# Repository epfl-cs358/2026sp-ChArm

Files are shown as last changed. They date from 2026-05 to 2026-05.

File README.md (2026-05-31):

# ChArm

<p align="center">
  
  
  
  
  
  
  
  
  
  
</p>

<p align="center">
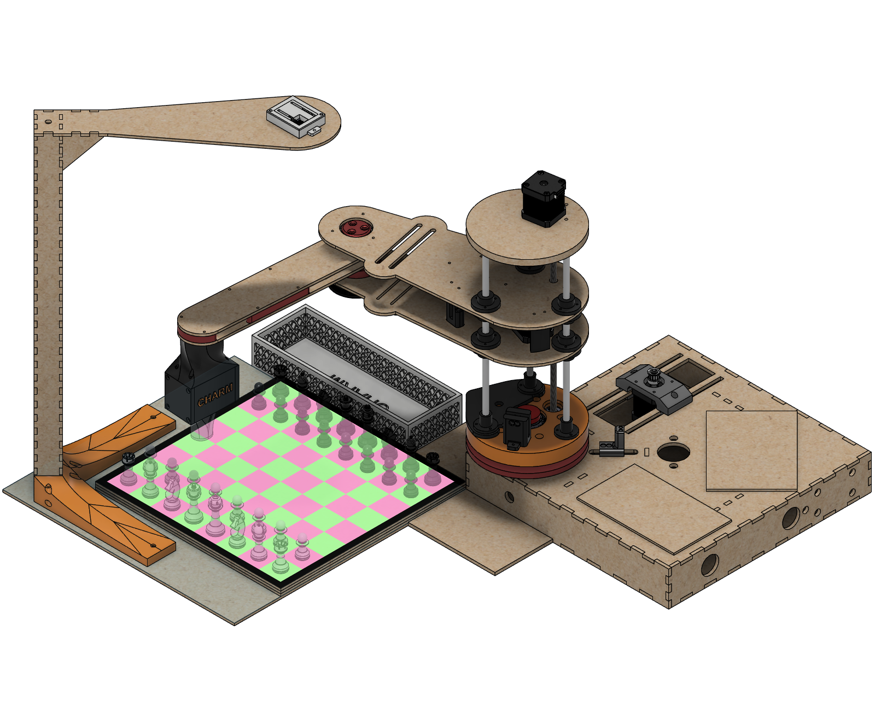
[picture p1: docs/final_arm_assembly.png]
Final arm assembly
  
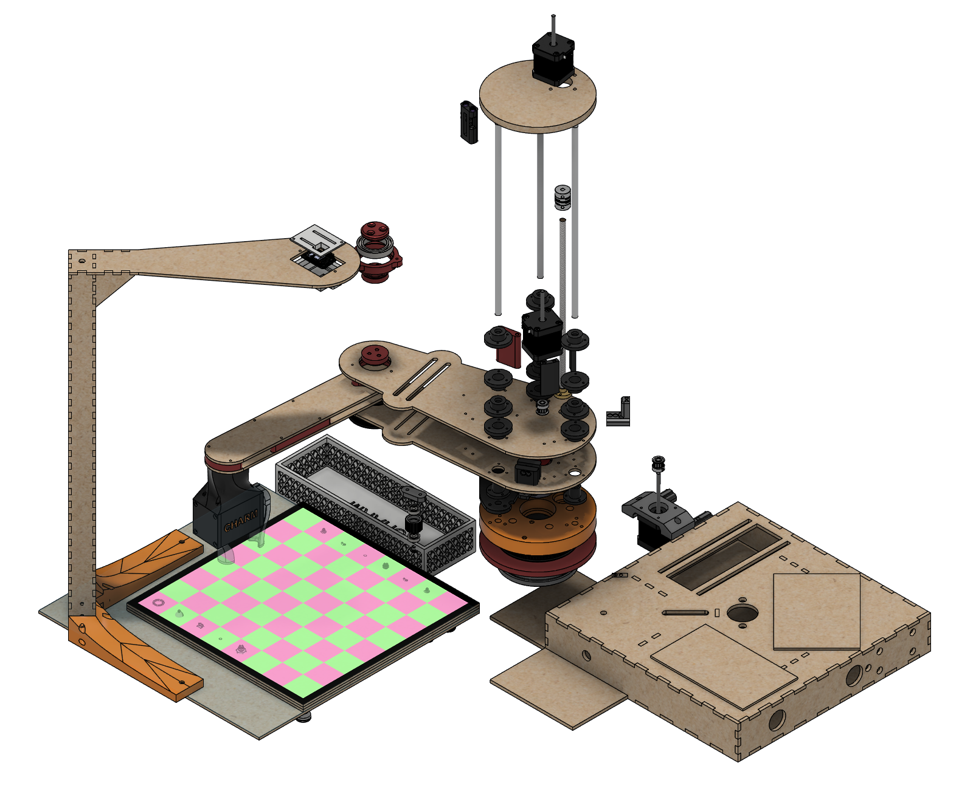
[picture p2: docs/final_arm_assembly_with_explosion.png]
Exploded final arm assembly
  
</p>

> A chess-playing robot arm that sees the board, thinks with Stockfish, and moves the pieces itself.

ChArm is a chess-playing robot arm built around a two-link SCARA arm with a vertical lead-screw Z axis and a servo gripper. An Arduino Mega handles motion, an ESP32-CAM captures the board, an ESP32 UI box drives an on-robot LCD/encoder interface, and a Python host runs the computer vision and chess logic that tie everything together.

<video src="https://github.com/user-attachments/assets/e374c072-53ec-447c-b2c5-00aa87391602" controls width="640"></video>

### Gameplay loop

1. The player initiates arm calibration.
2. The player starts a game and selects a difficulty and a color to play — from either the on-robot LCD/encoder UI or the webapp.
3. The player makes a move on the physical board and confirms it with the rotary encoder (or the **Player done** button in the webapp).
4. The ESP32-CAM captures an image of the board.
5. A computer-vision algorithm and/or a CNN turns that image into two bitmaps describing piece placement.
6. Stockfish computes the best response at the selected skill level.
7. The arm physically moves the chess piece on the board.
8. The turn passes back to the human; repeat from step 3.

This README is the top-level guide to understanding, rebuilding, and running the project.

## Table of Contents

- [Main Features](#main-features)
- [Repository Layout](#repository-layout)
- [Hardware](#hardware)
- [Software Architecture](#software-architecture)
- [How the Game Flow Works](#how-the-game-flow-works)
- [Setup & Installation](#setup--installation)
- [Web Interface](#web-interface)
- [Calibration](#calibration)
- [Common Workflows](#common-workflows)
- [Current Limitations](#current-limitations)
- [Future Improvements](#future-improvements)
- [License](#license)

## Project Overview

The project is organized so that hardware control and chess/vision logic can be developed and tested independently, then integrated through a single Python host.

## Main Features

**Gameplay**
- Plays a full game of physical chess against a human, end to end
- Selectable difficulty (1-20) powered by Stockfish
- Handles normal moves, captures, castling and promotion
- On-robot LCD + rotary-encoder UI — no computer needed to play

**Robot / motion**
- Two-link SCARA arm with a Z lead-screw and servo gripper
- Automatic homing via limit switches and EEPROM-persisted calibration
- Cartesian pick-and-place driven over serial from the Python host

**Computer vision**
- Wi-Fi board capture via ESP32-CAM
- Two-stage perspective rectification and 8×8 grid splitting
- CNN square classifier (empty / white / black) with a classical fallback pipeline
- Self-improving "living dataset" — corrected squares feed the next training cycle

**Move understanding**
- Reconstructs the human's move by matching the observed board against all legal moves
- Validates each observation (legal / unchanged / invalid / ambiguous) and re-captures bad frames

## Repository Layout

```text
2026sp-ChArm/
├── arduino_code/                 PlatformIO project for the Arduino Mega
│   ├── src/                      Firmware entry points and hardware classes
│   ├── esp32_cam_mega_bridge/    ESP32-CAM ↔ Mega bridge sketches
│   └── esp32_ui_box/             ESP32 UI box firmware
├── docs/                         Project documentation
│   └── CAD/                      Project CAD files
├── python_code/                  Python host-side code
│   ├── src/charm/
│   │   ├── vision/               Board calibration and image processing
│   │   ├── chess_engine/         Stockfish integration
│   │   ├── game/                 Board state tracking and orchestration
│   │   ├── arduino/              Serial and UI bridges
│   │   └── utils/                Shared helpers
│   ├── tests/                    Unit tests and demos
│   ├── play_game.py              Full game entry point
│   ├── main.py                   Vision / integration runner
│   └── capture_game_session.py   Raw image capture helper
├── Simulation/                   Prototyping / simulation files
├── webapp/                       Optional Next.js frontend
└── webapp_backend/               Optional FastAPI backend
```
## Hardware

### Mechanical

- **SCARA arm** — two 250 mm links (~500 mm reach), belt-reduced rotational joints
  - J1 (base): 20 → 160 tooth reduction
  - J2 (elbow): 18 → 105 tooth reduction
- **Z axis** — 290 mm-travel vertical lead screw (4-start, 2 mm pitch → 8 mm/rev)
- **Gripper** — servo-driven, 0°–65° open/close span
- **Camera arm** — fixed to the chessboard with a 3D-printed support screwed
  into the board, and a camera mount holds the ESP32-CAM at a stable viewing angle
- **Motors** — 3× 1.8° / 200-step steppers at 16× microstepping (the lead screw runs at 2× microstepping)

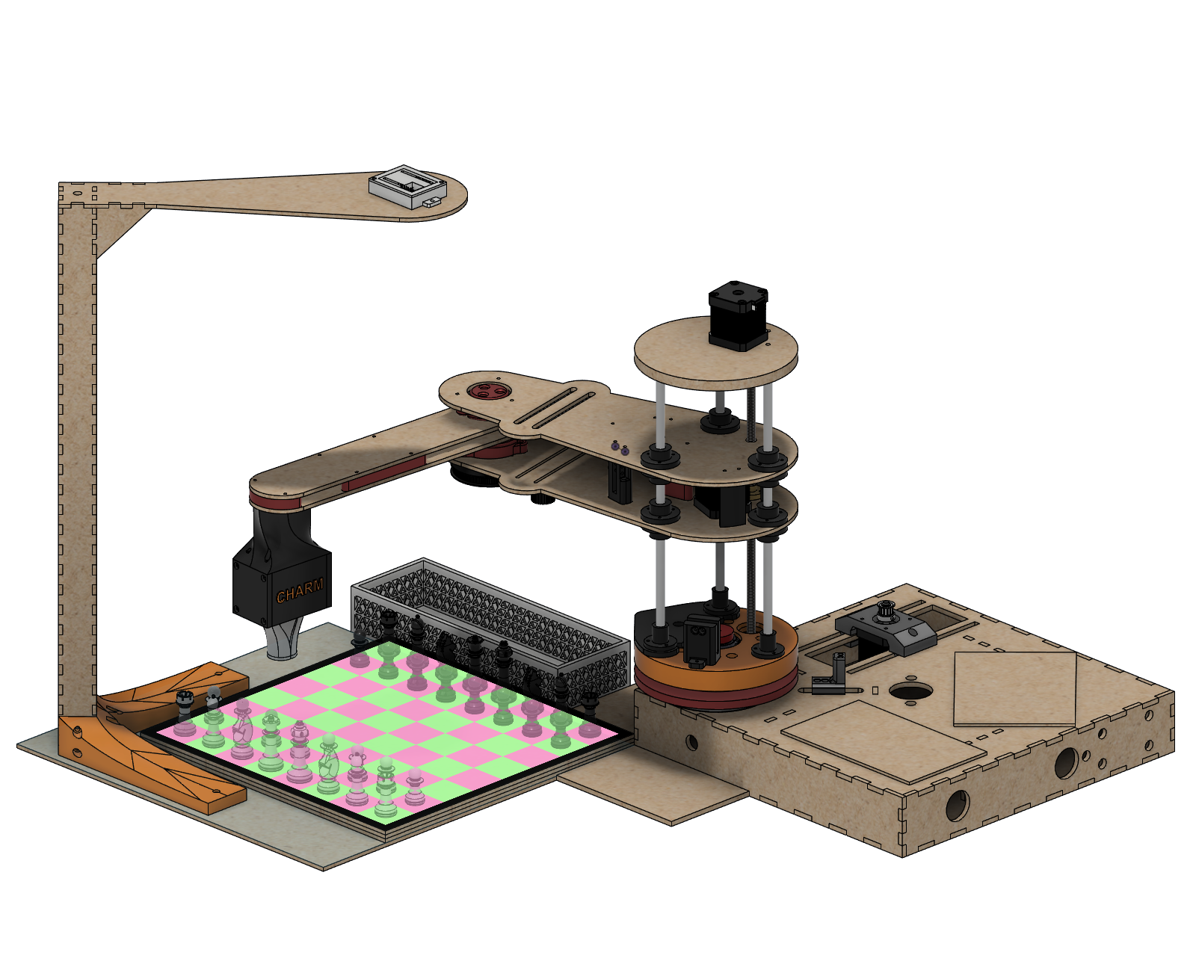
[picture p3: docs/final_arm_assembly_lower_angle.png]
CAD image of the final build


### Electronics and Wiring

**Main Arduino circuit**

- **Arduino Mega 2560** — motion control, calibration, EEPROM persistence
- **ESP32-CAM** (AI-Thinker) — Wi-Fi board capture, HTTP `/capture` endpoint
- **ESP32 UI box** — 16×2 LCD + rotary encoder/button, TCP link to host
- **3× STEP/DIR stepper drivers**
- **4× limit switches** — J1 home, 2× J2 home, Z bottom; wired to a stripboard in a pull-up configuration and read by the Arduino
- **Power supply** — 12 V at 5 A for the motors (through the CNC shield); a buck converter supplies the 5 V components (camera, servo, etc.)

**UI box**

- Needs only 5 V power, distributed to the correct pins on a stripboard. The data pins of the LCD and the button connect to an ESP32 that handles transmission to the host.

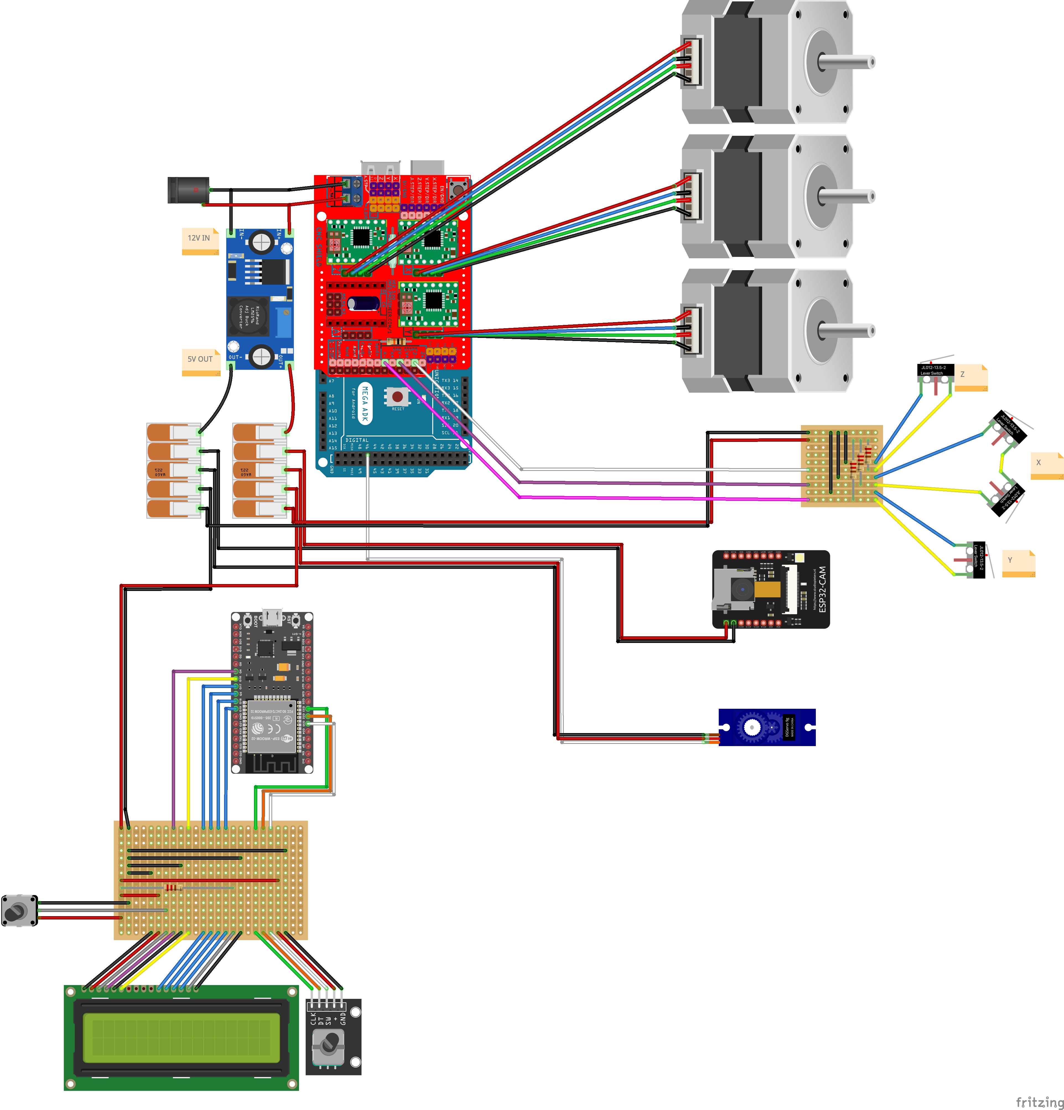
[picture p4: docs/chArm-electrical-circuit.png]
Electrical Circuit


### Fabrication Tools

- **Metal lathe and drill press** — machining the flanges at the base
- **3D printer** — most of the parts around the arm
- **Laser cutter** — structural parts that would not print well
- **Soldering equipment** — wiring and connectors

### CAD Overview

The CAD files for the printed and laser-cut parts live in [docs/CAD/](docs/CAD/).

**Build order (high level)**

1. Machine the base flanges, on the lathe/drill.
2. Print the 3D printed parts available in the CAD files
3. Laser cut the DXF files in the CAD files
3. Cut 3 320 size 8mm metal rods
4. There are a lot of heat inserts needed so make sure you put them nicely.
5. Once the heat inserts are inserted you can start building the 6 main modules to assemble (box, base, arm, lcd, display, camera arm, chessboard)
6. Next step is to solder and add jst connectors to the 4 main electrical components (one camera power stripboard, 1 ui box stripboard, the limit switch themselves and its pull up resistor stripboard)
7. Now that everything is assembled just wire up the electronics as in the diagram
8. flash the firmware using the ./install.sh utility
9. start playing

### Configuration Files

Two firmware headers hold the values worth checking whenever the robot is rebuilt or re-tuned:

- [config.h](arduino_code/src/hardware/src/config.h) — motion and geometry constants (gear ratios, link lengths, steps/mm, gripper angles, pick/place heights).
- [pins.h](arduino_code/src/hardware/src/pins.h) — the microcontroller pin assignments.

## Software Architecture

ChArm is a distributed system. A Python backend orchestrates the game and talks
to a web/embedded frontend, three microcontrollers, and a chess engine. The
backend (`webapp_backend/api_server.py`, a FastAPI service on port `8765`) is
the single source of truth: both the webapp and the on-robot LCD drive the
**same** game session through it.

```mermaid
flowchart LR
    WEB["Webapp<br/>(Next.js :3000)"]
    UI["On-robot UI<br/>ESP32 UI box"]
    CAM["ESP32-CAM"]
    ARM["Arduino Mega<br/>SCARA arm"]

    subgraph HOST["Python host — FastAPI backend (:8765)"]
        GAME["game/<br/>state tracker + controller"]
        VIS["vision/<br/>CV router → classical / CNN"]
        ENG["chess_engine/<br/>Stockfish + evaluation"]
        ADP["arduino/ + robot_adapter"]
    end

    WEB <-->|HTTP / REST| HOST
    UI <-->|TCP| HOST
    CAM -->|JPEG over Wi-Fi| VIS
    GAME --> VIS
    GAME --> ENG
    GAME --> ADP
    ADP -->|USB serial| ARM
```

The rest of this section documents each layer, bottom-up: the **embedded
firmware** on the microcontrollers, then the **Python host** modules.

### Embedded Firmware

Three microcontrollers each run their own firmware: the Arduino Mega for motion,
the ESP32-CAM for board capture, and the ESP32 UI box for the player interface.

#### Arduino Mega — motion control

The main Arduino entry point is [arduino_code/src/main.cpp](arduino_code/src/main.cpp).

It is responsible for:

- initialising steppers, joints, gripper, lead screw, and limit switches on boot
- homing all axes via limit switches before any motion
- running a guided 3-corner board calibration wizard (`cal` command) and saving the result to EEPROM
- receiving serial commands from the Python host and executing them
- translating high-level commands like `pick <piece> <square>` and `put <piece> <square|trash>` into Cartesian pick-and-place sequences
- supporting direct movement commands

Key hardware abstractions are in [arduino_code/src/hardware/src/](arduino_code/src/hardware/src/):

- `ScaraArm`: top-level arm controller; exposes `pickAt`, `placeAt`, `moveXY`, `moveXYZ`, `goHome`
- `ScaraKinematics`: inverse/forward kinematics for the two-link SCARA geometry
- `ScaraJoint`: per-joint stepper with gear-ratio scaling and angle tracking
- `LeadScrew`: Z-axis stepper with mm-to-step conversion
- `StepperXYZ`: low-level STEP/DIR stepper driver
- `Gripper`: servo-driven gripper with open/close angles
- `LimitSwitch`: debounced limit switch reader used during calibration

The PlatformIO environments are defined in [arduino_code/platformio.ini](arduino_code/platformio.ini).

#### ESP32-CAM — board capture

The ESP32-CAM firmware is in [arduino_code/esp32_cam_mega_bridge/esp32_cam_code_mit.ino](arduino_code/esp32_cam_mega_bridge/esp32_cam_code_mit.ino).

Upload it to an AI Thinker ESP32-CAM board with the Arduino ESP32 core. Before flashing, set the `ssid` and `password` constants in the sketch to the Wi-Fi network used by the Python host.

At runtime, the board:

- connects to Wi-Fi and starts an HTTP server on port `80`
- exposes `/capture` as a JPEG image endpoint for browser or Python capture
- exposes `/status` as a small JSON health endpoint
- exposes `/` as a camera settings endpoint

#### ESP32 UI box — player interface

The main ESP32 entry point is [arduino_code/esp32_ui_box/esp32_ui_box.cpp](arduino_code/esp32_ui_box/esp32_ui_box.cpp).

It is responsible for:

- connecting to Wi-Fi
- hosting a TCP server on port 8765 for bidirectional communication with the Python host
- driving the 16×2 LCD display
- reading the rotary encoder and push button and converting them to `INPUT_NEXT`, `INPUT_PREV`, and `INPUT_SELECT` events
- running the `UIState` mode state machine and forwarding commands to Python

Key abstractions are in [arduino_code/src/hardware/src/](arduino_code/src/hardware/src/):

- `UIState`: 11-mode state machine holding the current screen, game status, turn, and selected values
- `UIControllerESP32`: ties it all together: reads encoder events and TCP messages, drives `UIState` transitions
- `LCDDisplay`: 16×2 display driver
- `ButtonInput`: rotary encoder decoder, emits `INPUT_NEXT`, `INPUT_PREV`, `INPUT_SELECT`

From the player's perspective the flow is:

1. The LCD shows `Main Menu`; scroll with the encoder to `> Start Game`, `> Calibration` or `> Manual Control`, and press whichever to select.
2. After selecting `> Start Game`, The LCD shows `Difficulty` / `<n>`; scroll to adjust and press to confirm difficulty level.
3. The LCD shows `Play as...` / `> White` or `> Black`; scroll and press to confirm.
4. During the game the top line shows the turn (`White Turn` / `Black Turn`, prefixed with `CHECK` if in check); the bottom line reflects the bot's activity (`BOT thinking...` and `Bot moving` / `<uci.move>`). When it is your turn, the bottom line shows `If done press OK`; make your move on the board and press the button to confirm.
5. When the game ends the LCD shows `White Wins!`, `Black Wins!`, `Stalemate`, or `Draw`.
6. If something goes wrong at any point (illegal move, board detection failure, etc.) the top line shows `Illegal move !` or `Set up ERROR` and the bottom line shows the error detail; press the button to clear it and retry.

Before flashing, edit `WIFI_CREDENTIALS` in [arduino_code/esp32_ui_box/esp32_ui_box.cpp](arduino_code/esp32_ui_box/esp32_ui_box.cpp). The LCD shows the ESP32 IP address after Wi-Fi connects; enter that address in the webapp so the host can reach the UI box.

The UI box exchanges TCP commands with the Python host. The ESP32-to-Python commands are `CHECK_BOARD`, `PLAYER_DONE`, `SET_COLOR <n>`, `SET_DIFFICULTY <n>`, `CALIBRATION`, `PROMOTION_CHOICE <piece>` (user's pawn-promotion selection: q/r/b/n), `BOARD_OK_ACK`, `BOARD_FAIL_ACK`, and `BOARD_TIMEOUT`. In manual-control mode the ESP32 also sends `MANUAL_JOINT1_FWD`, `MANUAL_JOINT1_BWD`, `MANUAL_JOINT2_FWD`, `MANUAL_JOINT2_BWD`, `MANUAL_Z_FWD`, `MANUAL_Z_BWD`, `MANUAL_GRIPPER_OPEN`, and `MANUAL_GRIPPER_CLOSE`. Python replies with status updates such as `BOARD_OK`, `BOARD_FAIL`, `BOT_THINKING`, `BOT_MOVE <uci>`, `BOT_MOVING`, `BOT_PROMOTING <piece>`, `PLAYER_TURN_WHITE`, `PLAYER_TURN_BLACK`, `MOVE_DONE`, `CHECK`, `PROMOTION_NEEDED`, `GAME_OVER <reason>`, `ERROR_MSG <message>`, and `SET_MODE <n>`.

The PlatformIO environment is defined in [arduino_code/esp32_ui_box/platformio.ini](arduino_code/esp32_ui_box/platformio.ini).

### Python Host

At runtime the FastAPI backend wires together four packages under
`python_code/src/charm/`:

| Package | Responsibility |
|---|---|
| `vision/` | Capture → rectify → classify into two 8×8 occupancy/color bitmaps |
| `game/` | Track board state, reconstruct the human's move, orchestrate turns |
| `chess_engine/` | Stockfish move selection and position evaluation |
| `arduino/` | Serial/TCP bridges to the SCARA arm and the UI box |

#### Computer Vision (`vision/`)

The vision stack turns a single raw ESP32-CAM frame into two 8×8 bitmaps (white
pieces and black pieces) for the move tracker. It runs **two interchangeable
pipelines**, a classical CV algorithm and a trained CNN, that share the same
pre-processing and the same bitmap output format, selected at runtime by a
router (`cv_router.py`).

Key files: `pipeline.py`, `board_detector.py`, `grid_splitter.py`,
`occupancy_detector.py`, `piece_color_detector.py`, `cnn_classifier.py`,
`cv_router.py`, `four_point_calibration.py`, `calibrated_pipeline.py`.

##### Geometric pre-processing (shared)

Both pipelines start from the same stage, which transforms a raw,
perspective-distorted camera image into a normalized 8×8 board representation.

**Two-stage perspective warping** — two sequential homographies align the board:

1. **Global warp**: the four calibrated outer corners map to an 800×800 square.
2. **Inner refinement**: internal grid intersections refine that warp,
   correcting lens distortion and small geometric error so every square lands
   consistently.

**Grid splitting**

The refined image is divided into 64 `SquareCell` objects. Each cell contains:

- an RGB crop of one board square
- its row and column indices within the 8×8 grid

##### Classical pipeline — the vision algorithm

The high-level flow of the classical CV pipeline is:

1. Run occupancy detection on each cell to decide whether it contains any piece.
2. Run color detection only on occupied cells to classify them as white or
   black.
3. Assemble the final white/black 8×8 bitmaps and save debug overlays for
   inspection.

**Occupancy detection**

For each square, the detector looks at a central region of interest instead of
the whole cell. The ROI is converted to grayscale, broad lighting gradients are suppressed by subtracting a heavily blurred version of the image, and then CLAHE is applied before scoring with the edge density with Canny .

The final occupancy score combines local contrast and Canny edge density.

For occupancy, `occupancy_threshold` decides whether a square is occupied.
Raising it reduces false positives, lowering it helps detect weaker pieces. In our setup, empty squares are usually around `0-5`, occupied squares around `20+`, and the active threshold is `12.0`.

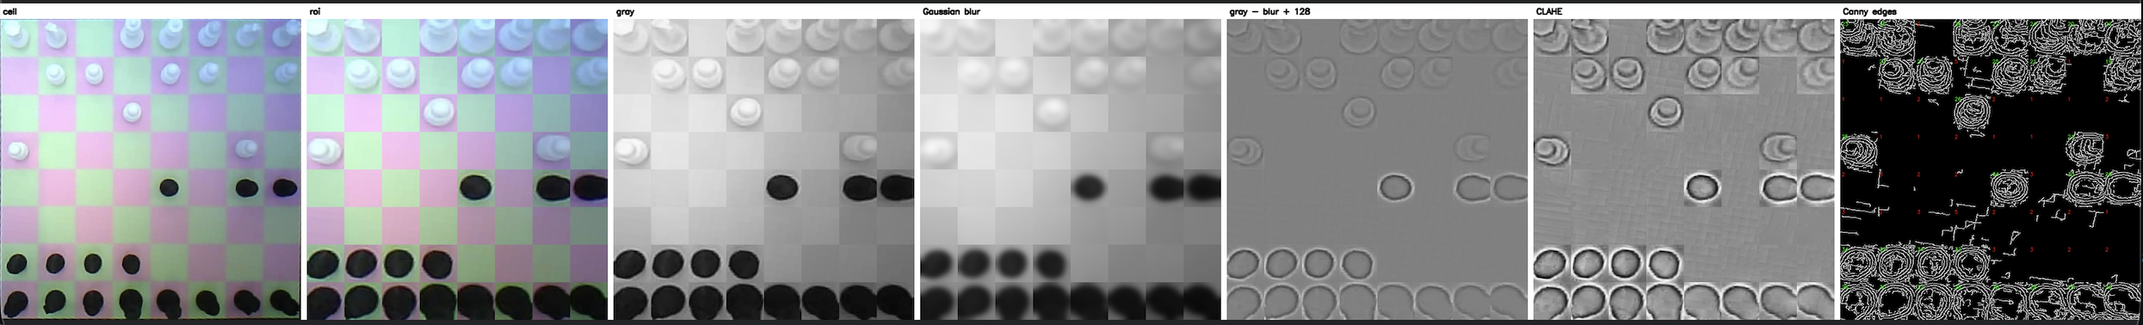
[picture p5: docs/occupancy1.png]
Occupancy Pipeline : from raw picture to processed.

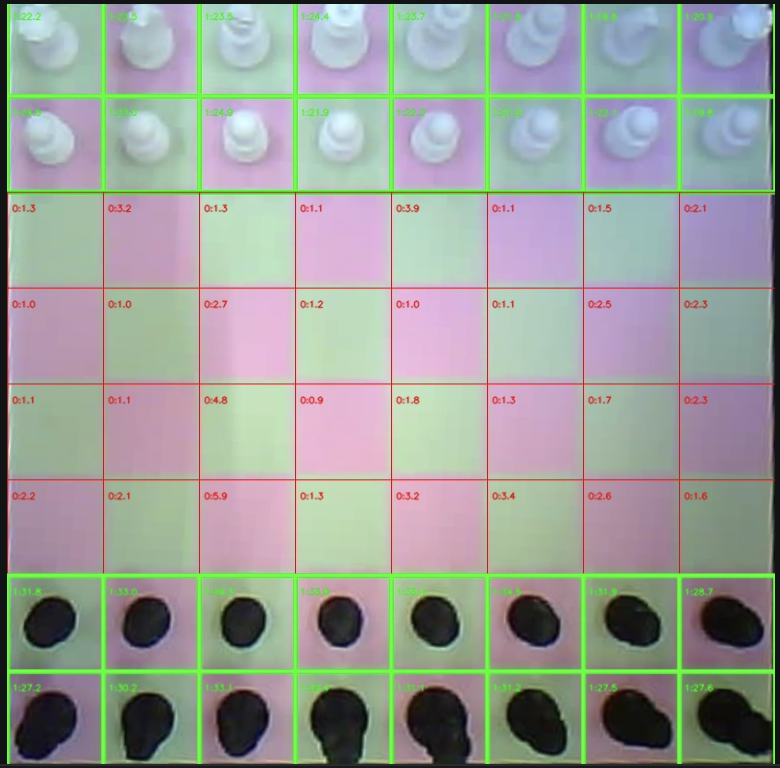
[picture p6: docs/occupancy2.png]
Final processed image with occupied tiles flagged


**Piece-color detection**

Only cells already marked as occupied are classified by color. For each occupied
cell, the detector inspects a smaller central ROI where the body of the chess
piece is most likely to appear. It converts that ROI to grayscale and uses the
75th percentile brightness as the color score.

For piece color, raising the threshold makes the detector more conservative
about white pieces, so borderline pieces are more likely to be classified as
black. Lowering the threshold makes pieces easier to classify as white. In our
setup, `90` separates white pieces around `200` from black pieces around `40`.

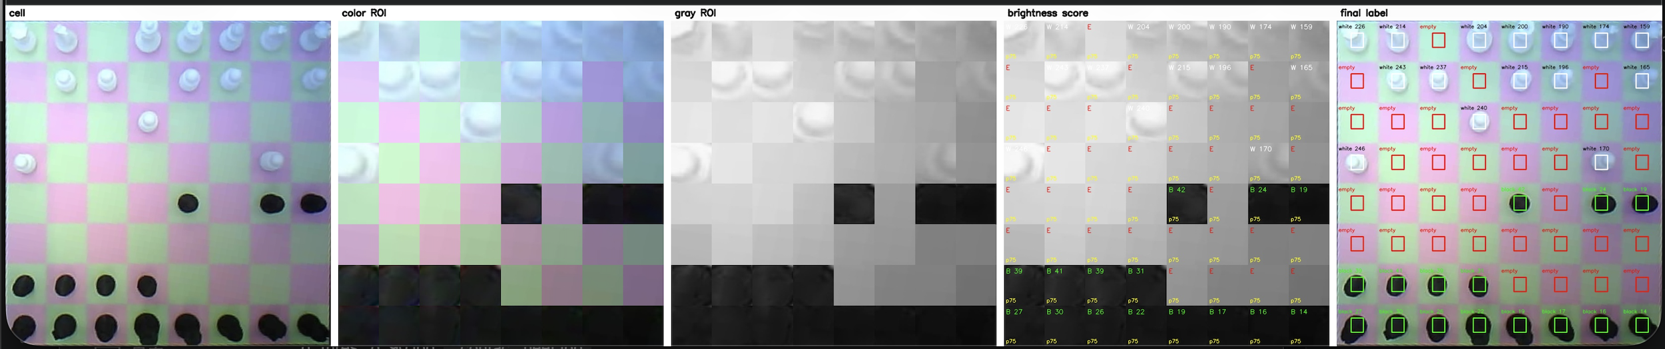
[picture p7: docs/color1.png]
Color detection pipeline, from raw picture to colors detected


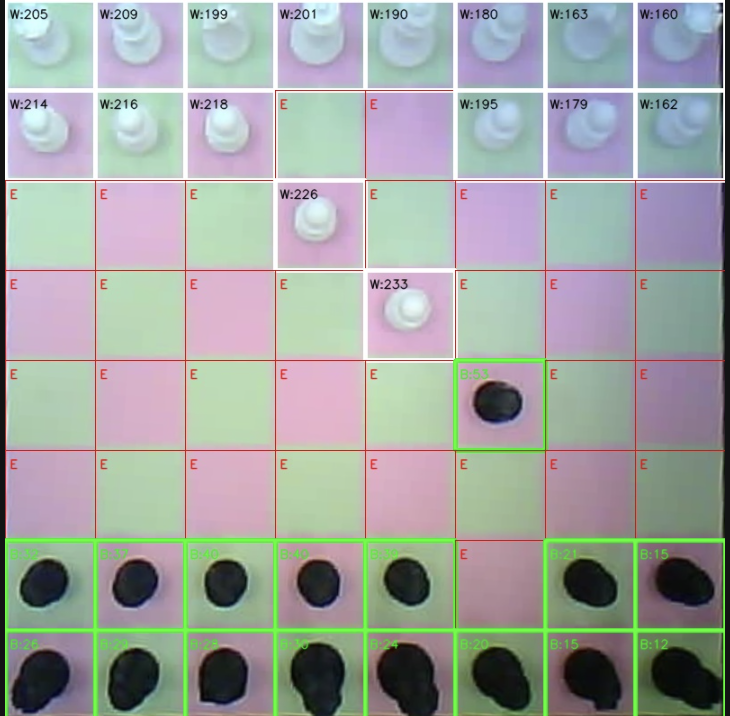
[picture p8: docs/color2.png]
Final color detected image with black and white pieces flagged


##### CNN classifier

The CNN classifier (`cnn_classifier.py`) replaces step 4 of the classical
pipeline (occupancy + color thresholds) with a single learned model trained on
the ChArm board and piece set by `train_cnn.py`. `CnnBoardClassifier` wraps a
trained **Keras / TensorFlow** model, loaded once and reused across requests.

**Model objective**

The classifier predicts one of three classes for each square:

- `empty`
- `white`
- `black`

**Model structure**

A lightweight Keras CNN runs efficiently on CPU:

- input: normalized RGB square image
- three convolutional blocks with increasing filter counts
- max-pooling for spatial downsampling
- global average pooling for robustness to slight piece offsets
- softmax output over the three classes

**Batch inference**

Instead of processing cells individually, all 64 board squares can be stacked into a single tensor and passed through the model in one forward pass. This allows the whole board to be evaluated efficiently and consistently.

##### Primary / fallback routing (`cv_router.py`)

To stay robust under shadows, blur, or unclear piece placement, the router
attempts multiple captures and evaluates them in sequence:

1. first attempts use the primary pipeline (typically the CNN)
2. if repeated fresh captures still fail to produce a valid board update, the
   system falls back to the other pipeline (the classical algorithm)
3. only observations that can be matched to a valid board-state transition are
   accepted

**Validation rule**

An observation is only accepted if the `BoardStateTracker` can interpret it as:

- a unique legal move

If the result is invalid or ambiguous, the frame is rejected and a new capture
is requested.

##### Living dataset and continuous improvement

The CNN improves from real operation through a correction loop: when a square is
misclassified, the user relabels it, the cell crop is added to the dataset, and
the next training run includes it. Over time the model specializes to the actual
board texture, lighting, pieces, and camera noise — reducing reliance on
hand-tuned thresholds.

#### Move Understanding (`game/`)

The `game/` package is the reasoning layer between camera perception and chess
rules. Vision tells the system what the physical board appears to contain;
`game/` decides whether that observation makes sense as a legal chess position
and updates the internal `python-chess` board accordingly.

A key design decision is to keep the camera's job simple. ChArm does **not** try
to visually identify whether a piece is a queen, bishop, knight, and so on.
Instead, the vision stack outputs two 8×8 occupancy maps:

- white-occupied squares
- black-occupied squares

The missing piece identity is recovered from context. Since the software already
knows the previous legal chess position, `BoardStateTracker` can simulate every
legal move from that position, convert each candidate board into the same
white/black occupancy format, and compare it against the observed bitmaps. If
only one legal move explains the new board, the move is accepted. This avoids the
fragile problem of recognizing six piece types from a noisy camera image and
turns move detection into a rules-based consistency check.

Each scan is classified into one of four tracker states:

| Status | Meaning |
|---|---|
| `accepted_legal_move` | One legal move uniquely explains the observed board. The move is pushed to the internal board. |
| `unchanged_position` | The observed board still matches the previous position, so no move has been made yet. |
| `invalid_observation` | No legal move explains the observation. The frame is rejected and the user is asked to correct the board or scan again. |
| `ambiguous_observation` | Multiple legal moves produce the same occupancy result. The frame is rejected because the move is not uniquely recoverable. |

Key files and main ideas:

##### `state_tracker.py`

This is the core of move understanding. It keeps the current `python-chess`
board and tries to explain a new camera observation using legal chess moves.

The main idea is simple: instead of asking the camera "which exact piece is on
each square?", we ask the chess engine "which legal move would make the board
look like this?" For each legal move, the tracker simulates the move, turns the
candidate board into white/black occupancy bitmaps, and compares those bitmaps
with the camera result.

If one move matches, the tracker accepts it and updates the board. If nothing
matches, the scan is rejected. If several moves look the same from occupancy
alone, the scan is marked ambiguous. This file is intentionally independent from
the camera, webapp, LCD, and robot arm, which makes the logic much easier to
test and reuse.

One special case is promotion: the camera cannot tell whether a pawn promoted to
a queen, rook, bishop, or knight because all of those look like "one piece on
the promotion square" in the bitmap. The tracker uses queen promotion as the
default during inference, and the UI can correct the final piece choice later.

##### `vision_integration.py`

This file is the bridge between image processing and the tracker. It runs the
board-vision pipeline on an image, takes the resulting white/black bitmaps, fixes
orientation if needed, and passes the bitmaps into `BoardStateTracker`.

The reason for this small adapter is cleanliness. The tracker should not care
where the bitmaps came from, and the vision code should not need to know the
details of chess move inference. If the camera calibration or vision pipeline
changes later, this is the main place where the two sides reconnect.

##### `game_session.py`

`GameSession` manages one full logical game. It sits one level above the tracker:
the tracker answers "what move happened?", while the session keeps track of
"has the game started?", "which color is the player?", "whose turn is next?",
and "what should the system tell the user?"

It validates the initial board, stores the player and robot colors, processes
the player's move, asks Stockfish for the robot's move, records the move history,
and commits the robot move after the arm has executed it. It also converts low
level tracker results into clearer messages, such as unchanged board, illegal
move, ambiguous scan, or the player still being in check.

The useful design choice is that `GameSession` still does not directly control
the camera or motors. It receives an image or bitmap, updates the logical chess
state, and returns a structured result. That means the game logic can be tested
without plugging in the real hardware.

A normal session looks like:

```text
validate initial board
    ↓
choose player color
    ↓
detect player move
    ↓
compute robot move
    ↓
arm executes robot move
    ↓
commit or verify robot move
```

##### `game_controller.py`

`GameController` connects the clean game logic to the actual running system. It
listens to events from the ESP32 LCD box, calls the CV router when a board scan
is needed, talks to `GameSession`, sends robot moves to the Arduino layer, and
keeps the webapp updated.

This is where the real-world flow is coordinated: checking the initial board,
handling "player done", retrying CNN/classical vision scans, showing errors,
displaying check/game-over states, applying difficulty settings, handling
promotion choices, and starting the robot move without freezing the UI.

The main idea is separation: if someone wanted to rebuild ChArm with a different
screen, camera trigger, or robot controller, they could keep the tracker and
session logic mostly unchanged and rewrite this controller layer for their own
hardware.

A typical player-move update follows this path:

```text
player presses done
    ↓
CV router captures board image
    ↓
CNN or classical vision pipeline
    ↓
white/black occupancy bitmaps
    ↓
BoardStateTracker
    ↓
accepted / unchanged / invalid / ambiguous result
    ↓
GameSession and GameController update the game flow
```

This separation is useful for debugging. Vision can be inspected as bitmaps and
debug overlays, while the move tracker can be tested without a camera by feeding
synthetic bitmaps generated from known chess moves.

#### Chess Engine (`chess_engine/`)

The `chess_engine/` package is the robot's chess-decision layer. It receives the
current `python-chess` board from the session, asks Stockfish to search that
position, and returns the move the robot should play.

Key files:

- `best_move.py` — opens a Stockfish UCI process, applies the selected strength
  settings, searches for a move under the configured think time, and returns a
  `python-chess` move object. Difficulty can be controlled through Stockfish
  skill level or through the `UCI_LimitStrength`/`UCI_Elo` options.
- `evaluation.py` — runs evaluation probes for the webapp and LCD feedback. It
  reports centipawn or mate scores, best-move suggestions, winning side,
  approximate win percentage, and player move ratings such as `Excellent`,
  `Mistake`, or `Blunder`.

The engine layer is intentionally separated from the rest of the game logic. The
tracker decides what the human physically did; Stockfish decides what the robot
should do next. Because those responsibilities are separate, the team can tune
difficulty, change think time, replace the engine, or adjust evaluation feedback
without touching the vision or move-reconstruction code.

A normal engine call looks like this:

```text
current python-chess board
    ↓
best_move.py
    ↓
Stockfish search at selected difficulty
    ↓
robot move in UCI format, e.g. e7e5
    ↓
GameController sends the move to the robot-motion layer
    ↓
GameSession commits the robot move to the internal board
```

After Stockfish returns a move, the game controller converts it into the robot's
physical pick-and-place sequence using the pre-move board state, so captures,
castling, en passant, and promotions can be handled consistently at the boundary
between chess logic and robot motion.

#### Hardware Bridges (`arduino/`)

- `arduino_bridge.py`: sends Cartesian pick-and-place commands to the Arduino Mega over USB serial
- `uiController_bridge.py`: `ArduinoUIControllerLink`, the TCP link to the ESP32 UI box

The backend's `webapp_backend/robot_adapter.py` owns the serial connection and a
lock, so the LCD and the webapp can both drive the arm without colliding.

## How the Game Flow Works

At a high level:

1. `./start.sh` launches the host backend (`webapp_backend/api_server.py`) and the webapp.
2. The backend connects to:
   - the **ESP32 UI box** over TCP (`ArduinoUIControllerLink`)
   - the **Arduino Mega** over USB serial (`robot_adapter`)
   - the **ESP32-CAM** over Wi-Fi for board capture

   The LCD and the webapp share this one backend, so either can drive the game.
3. The user starts the game from the UI (or webapp) and picks color and difficulty.
4. The backend validates the initial board from a calibrated image.
5. After each player move, the backend:
   - captures a new board image,
   - runs the vision pipeline,
   - reconstructs the move with `python-chess`,
   - validates whether the observation is acceptable.
6. Stockfish computes the robot response.
7. The Arduino executes the robot move physically.

The tracker statuses currently used by the move-validity layer are:

- `accepted_legal_move`
- `unchanged_position`
- `invalid_observation`
- `ambiguous_observation`

## Setup & Installation

We provide a cross-platform setup wizard and launcher scripts that run on **Windows, macOS, and Linux**.

### What the Setup Wizard Does
The setup wizard automates the entire installation and deployment pipeline:
1. **Prerequisite Check**: Verifies that Python 3 and Node.js/NPM are present on your machine.
2. **Python Environment**: Automatically creates a local virtual environment (`venv/` in the root) and installs all required dependencies (including **PlatformIO** so you do not need Arduino IDE).
3. **Frontend Dependencies**: Installs React/Next.js frontend libraries in the `webapp/` folder.
4. **Firmware Wizard**: Runs a step-by-step firmware compiling and uploading flow. It automatically scans your computer's USB/Serial ports, displays them, and lets you select the correct port for:
   - **ESP32-CAM** (Mega Bridge)
   - **ESP32 UI Box**
   - **Arduino Mega 2560**
5. **Startup Shortcuts**: Creates root launcher scripts (`start.sh` for Linux/macOS, `start.bat` for Windows) targeting the virtual environment.

---

### Step 1: Run the Installation Script

1. **Linux / macOS**:
   ```bash
   ./install.sh
   ```
2. **Windows**:
   Double-click or run from CMD:
   ```cmd
   install.bat
   ```

Follow the prompts to configure Node dependencies and select your serial ports to flash the hardware controllers.

> [!NOTE]
> Make sure to install Stockfish separately if it is not already available on your machine:
> - **Debian/Ubuntu**: `sudo apt install stockfish`
> - **macOS**: `brew install stockfish`
> - **Windows**: Download the binary from the official Stockfish site and add it to your PATH.

---

### Step 2: How to Launch the App

Once setup is complete, you can launch both backend and frontend servers with a single command:

1. **Linux / macOS**:
   ```bash
   ./start.sh
   ```
2. **Windows**:
   ```cmd
   start.bat
   ```

This will automatically load the virtual environment and start the FastAPI webserver and React dashboard concurrently.

## Web Interface

Once the app is running, open the webapp at <http://localhost:3000>. It is the
control center for the whole robot: you can play a game, configure the vision
pipeline, train and activate a CNN, label training data, and calibrate the arm —
all without touching a terminal.

### Built-in Guide page

The webapp ships with its own **Guide** page that walks through every screen,
explains what each control does, and ends with a "Starting a Game" checklist. It
lives at <http://localhost:3000/guide> and is the most up-to-date, canonical
reference for using the interface — start there rather than memorizing the
sections below.

### Pages at a glance

| Page | Route | What it's for |
|---|---|---|
| Dashboard | `/` | Play a game, live board view, arm calibration, **Run LCD** sync |
| Vision Pipeline | `/lab` | Debug the classical CV output stage-by-stage; tune the occupancy threshold and warp |
| Vision Settings | `/lab/vision-settings` | CV router (classical vs. CNN), auto-save of training frames, active CNN model |
| Labeling Wizard | `/lab/labeling` | Build labeled datasets via arm-driven capture or bulk painting |
| CNN Wizard | `/lab/cnn` | Train a model on a dataset and activate it for live play |
| SCARA Calibration | `/robot` | Teach the arm the board corners (a1, h1, h8) |
| Guide | `/guide` | In-app walkthrough of all of the above |

The Serial Monitor bar at the bottom of every page streams the commands sent to
the Arduino arm (TX) and its responses (RX) for live debugging.
## Calibration

The camera image contains a lot more than the chessboard: table texture, shadows,
robot parts, board borders, lens perspective, and sometimes pieces near the edge
of a square. Instead of trying to detect the 8×8 grid directly from that noisy
full image, ChArm uses a two-step crop-and-warp calibration.

The idea is:

1. first find the outer board area and warp it into a square top-down view,
2. then select the cleaner inner playing area used for the 8×8 grid.

This makes the vision pipeline more stable because the later CNN/classical
detectors only see the board region they actually need, not the surrounding
background noise.

The Python vision stack saves this setup in two JSON files:

- `python_code/board_calibration.json`
- `python_code/inner_warp_calibration.json`

The related vision code lives in:

- `python_code/src/charm/vision/four_point_calibration.py` — stores and applies
  the outer-board and inner-warp perspective transforms.
- `python_code/src/charm/vision/calibration_config.py` — defines the default
  calibration file locations.
- `python_code/calibrate_aruco.py` — can generate the calibration files from
  ArUco markers.
- the webapp manual calibration flow — lets the user adjust and save the two
  calibration steps visually.

The typical workflow is:

1. capture a clear image of the board,
2. mark the four outer board corners,
3. warp the image into a first top-down board view,
4. mark the inner playable area more precisely,
5. save both calibration JSON files,
6. run the game pipeline using the refined board crop.

After calibration, every live image follows the same path: raw camera photo →
outer board warp → inner refined warp → 64 square crops. This is the main reason
the rest of the vision system can stay simple and consistent.

## Common Workflows

### Play a game

This is the normal way to run ChArm. From the repo root:

```bash
./start.sh
```

`start.sh` runs `npm run dev`, which launches **both** the Python vision/game
backend (`webapp_backend/api_server.py`, port `8765`) and the Next.js frontend
(port `3000`). Then either:

- open the webapp at <http://localhost:3000>

From there: calibrate the arm (mandatory), start a game, pick color and difficulty, make
your move on the physical board, and confirm it. The backend captures the board,
runs the vision pipeline, validates your move, asks Stockfish for the reply, and
drives the arm.

### Calibrate the board (vision)

The board calibration is done from the webapp:

1. Click **Manual calibration**.
2. Capture a new picture.
3. Adjust the outer corners, then the inner warp — click **Save** and
   **Calibrate** between each step.

This writes `board_calibration.json` and `inner_warp_calibration.json`, which the
game pipeline then loads automatically.

### Improve the CNN (living-dataset loop)

Training data accumulates in `python_code/labeled_datasets/`. There are two ways
to grow it.

**During play (passive)** — every validated board frame is sliced into 64
labeled cell crops and saved automatically, so the dataset grows just by playing.

**With the labeling wizard (webapp)** — the webapp has a dedicated labeling page
for building datasets quickly and consistently. It supports two capture modes:

- **Autonomous (arm-driven) capture** — the robot picks pieces from a source
  square and places them across the board on its own, homing out of frame before
  each shot. This produces large, correctly-labeled datasets with no manual
  effort, since the label is whatever the arm just placed.
- **Bulk painting** — the "painted-board" mode: set up many pieces at once, paint
  each square's label (empty / white / black) on the on-screen grid, then hit
  capture. One photo yields a labeled crop for every painted square.

<table>
  <tr>
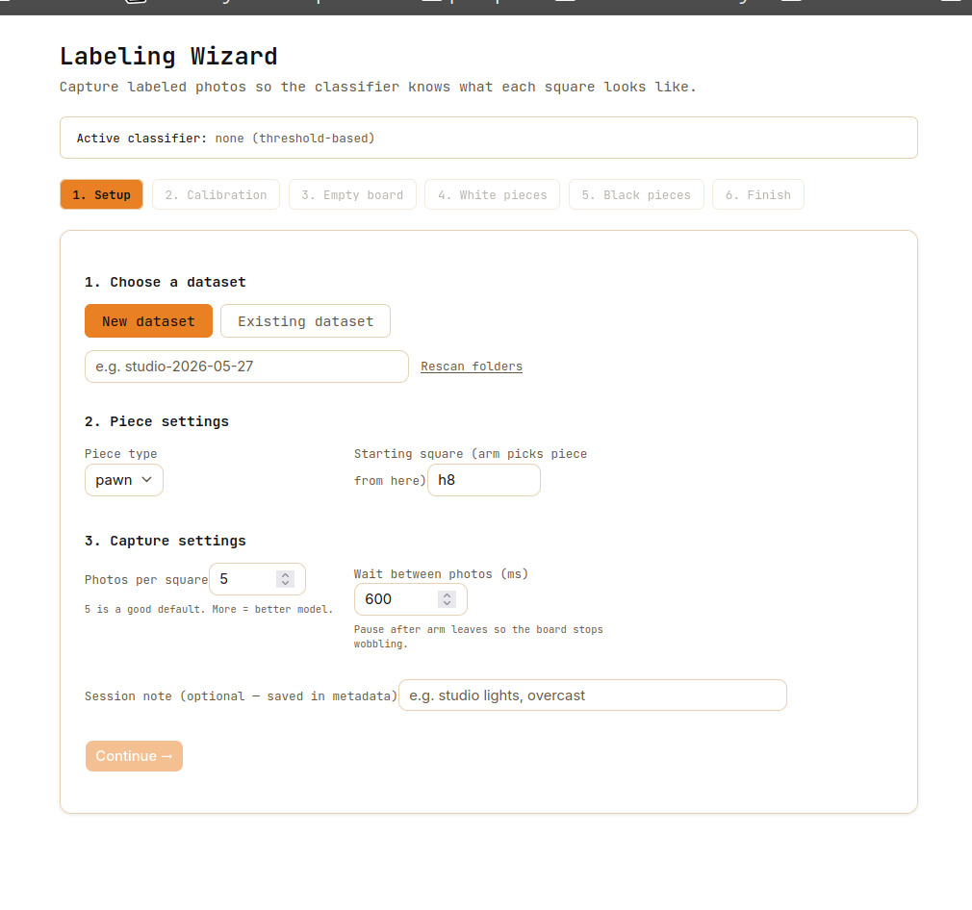
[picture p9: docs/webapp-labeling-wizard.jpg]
    <td align="center"><br><sub>Labeling Wizard</sub></td>
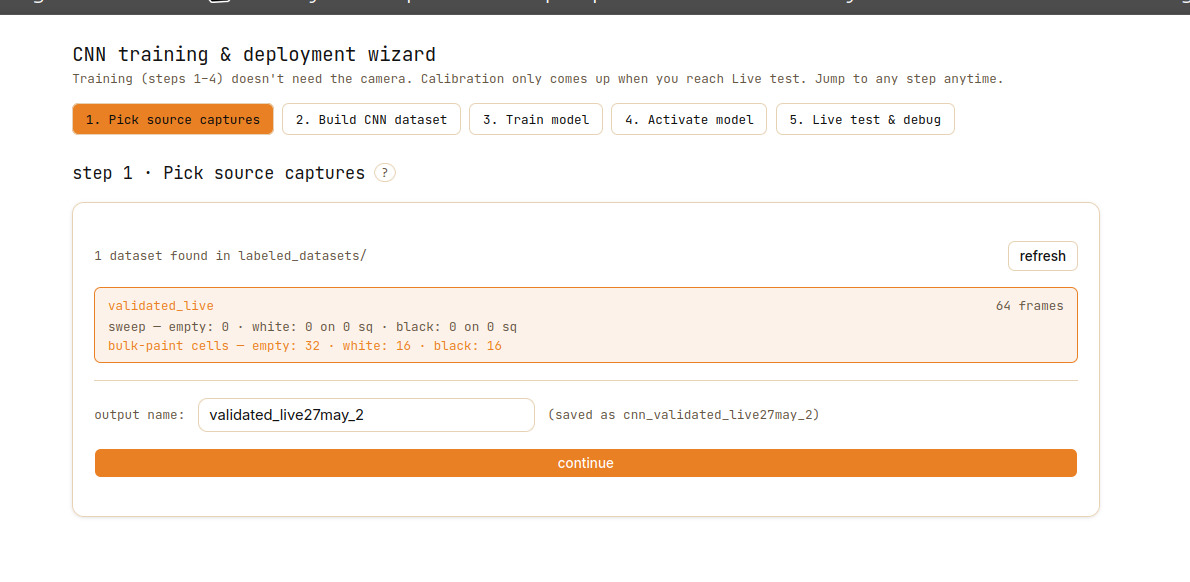
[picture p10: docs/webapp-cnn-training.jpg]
    <td align="center"><br><sub>CNN Wizard — training</sub></td>
  </tr>
  <tr>
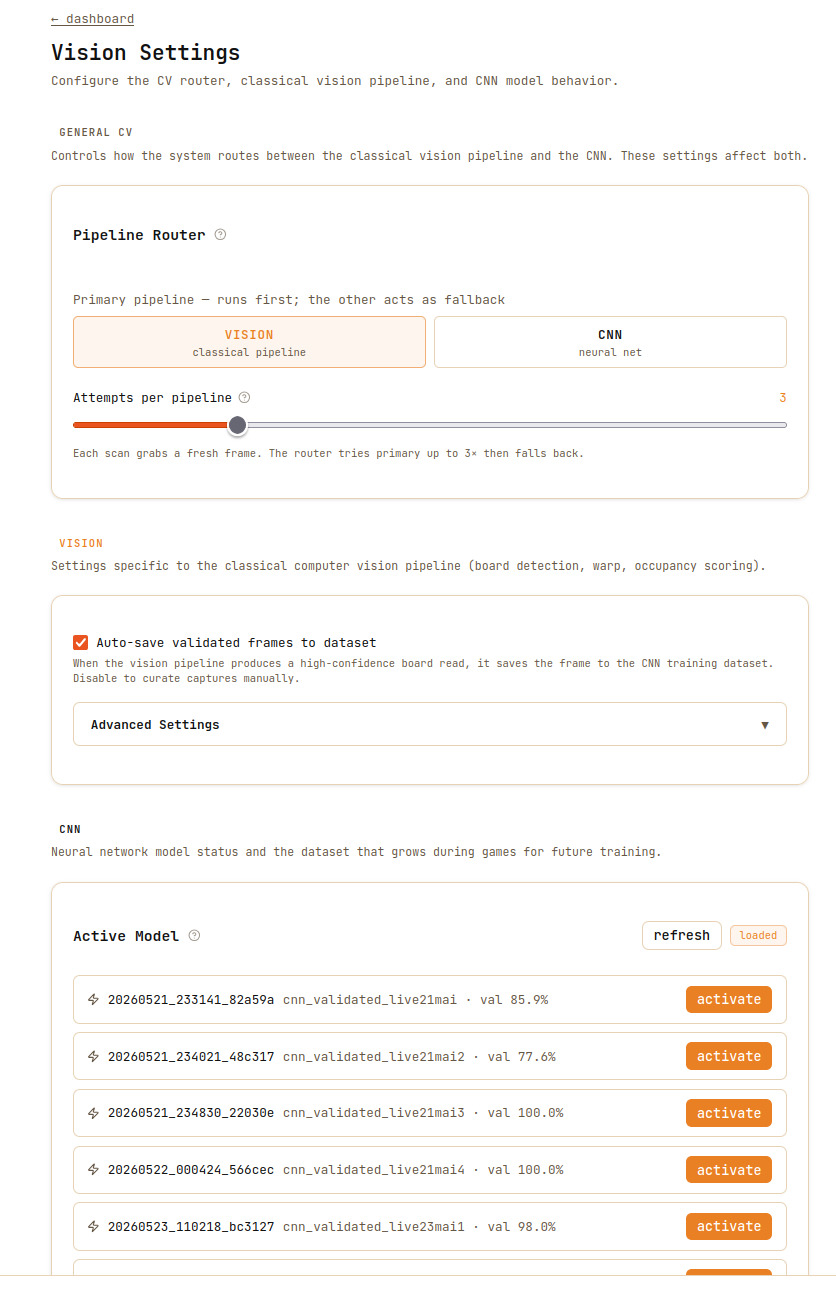
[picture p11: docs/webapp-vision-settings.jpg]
    <td align="center"><br><sub>Vision Settings</sub></td>
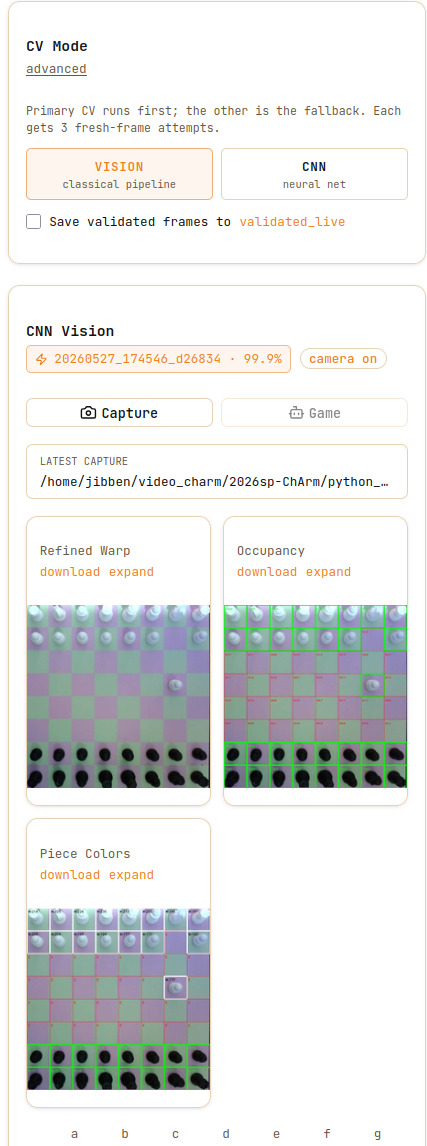
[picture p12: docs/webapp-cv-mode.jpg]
    <td align="center"><br><sub>Vision Pipeline</sub></td>
  </tr>
  <tr>
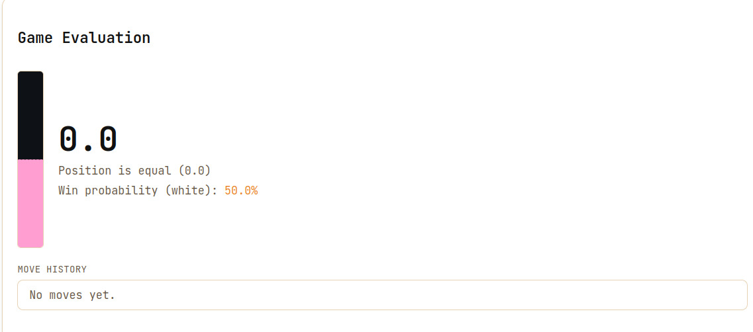
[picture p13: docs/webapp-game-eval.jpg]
    <td align="center" colspan="2"><br><sub>Dashboard — game &amp; evaluation</sub></td>
  </tr>
</table>

**Train and deploy** — once a dataset looks good (the wizard can also compute
per-square accuracy stats), build and train:

```bash
source venv/bin/activate
# optional: review crops one-by-one and drop bad ones
python python_code/validate_labels.py
# train on a prepared dataset folder
python python_code/train_cnn.py --dataset cnn_<name> --epochs 20
```

The resulting model is then used by the CNN classifier for the next session.

## Current Limitations

- The move tracker currently works from **occupancy + piece color**, not full piece identity.
- Because of that, the system relies on a **known previous chess position** and infers the move by iterating over legal moves.
- Promotion cannot be uniquely identified from occupancy/color alone if multiple promotion pieces would produce the same bitmap pattern.
- Real-world robustness still depends on lighting, calibration quality, and board visibility.

## Future Improvements

Some realistic next steps are:

### Mechanical

- Increase arm speed while preserving repeatability and positional accuracy.
- Design a better enclosure/box for cleaner integration of electronics and mechanics.
- Improve stepper-driver heat management to reduce overheating risks during longer runs.
- Machine out of aluminium critical joint components, especially the axle section linking the forearm to the joint pulley, to improve rigidity and reduce play.
- Reduce backlash and improve overall structural stiffness in the SCARA linkage.

### Vision and Software

- Add automated retraining workflows for the continuously growing dataset.
- Strengthen end-to-end robustness across different lighting conditions and camera positions.

### LCD / Embedded UI

- Add an in-game pause menu during the player's turn with forfeit and mid-game calibration options.
- Show a processing indicator while the vision pipeline runs after the player confirms a move, so the LCD does not appear stuck on "If done press OK".

### System Integration

- Add clearer player feedback when invalid or ambiguous board states are detected.
- Improve synchronization between board verification, move planning, and robot execution.

## License

Hardware designs are licensed under
[Creative Commons Attribution 4.0](LICENSE-CC-BY-4.0).

Unless otherwise noted, the code in this repository is licensed under the
[MIT License](LICENSE).

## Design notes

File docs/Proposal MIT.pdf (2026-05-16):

# ChArm Proposal

Making Intelligent Things - CS358(b)

Allan Burnier, Sipke Fokkema, Tamara Horak, Nika Horvat, Fazil Souissi, Haobin Wang, Jiayi Zhang

CS-358 Making Intelligent Things | ChArm Proposal
EPFL | 29.03.2026

# Introduction

Our project aims to design and build a SCARA robotic arm capable of autonomously moving chess pieces on a board. By integrating computer vision for board state recognition and a chess engine for decision-making, the system can play complete games against a human opponent. This combination of precise mechanical control and intelligent software creates an interactive and automated chess-playing platform.

## Main parts of the scara chess build

### Chessboard and pieces

A custom-designed chessboard along with all 32 chess pieces, optimized for reliable detection and manipulation by the robotic system.

### SCARA arm base

A stable enclosure that houses the mechanical structure, electronics, and control components of the SCARA arm.

### SCARA Arm

The primary robotic assembly responsible for precise movement and positioning, enabling accurate manipulation of chess pieces across the board.

### Camera Arm

A dedicated support structure that positions a camera above the chessboard, allowing for real-time computer vision and board state recognition.

# Detailed Description

## Mechanical

The main arm assembly will consist of 4 main parts.
Here is a sketch to see what the position of each element will be and how it will all get together with the chess board in place

### The arm base

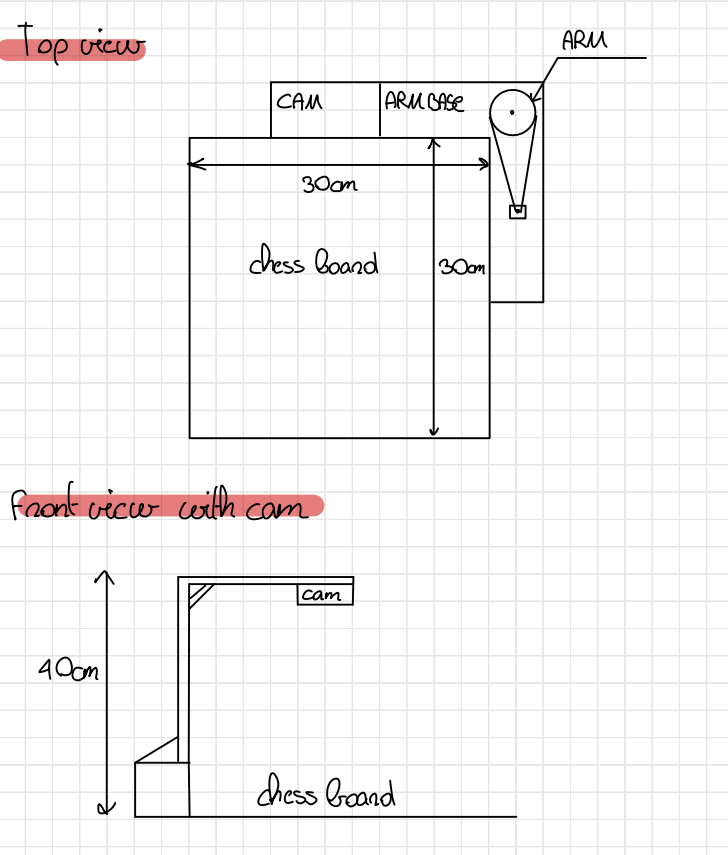
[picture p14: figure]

The arm base will be a box laser cutted out of MDF. The only constraint on it is its position since to cover the maximum range it needs to be in one of the angles of the chessboard.

The base will have to serve multiple purposes.
- provide stability Since our arm will be ~50cm long it has a potential to fall over. So the base will need to be heavy enough.
- Cable management the box will have an opening on one of the sides to allow routing cables, motor drivers, the arduino and different cables needed.
- Screen mount our build will also have a small lcd screen and a few buttons to interact with the robot arm. The Screen will be mounted on that base.

### The camera arm

A minimalist structure to hold the camera on top of the chess board. It will have to be taller than the robot arm so it doesn’t get into the way of the SCARA arm. It will be made out of MDFand have a hanger like structure with 3D printed links.

### The SCARA arm

The arm is the main assembly of our project. It will have three degrees of freedom.

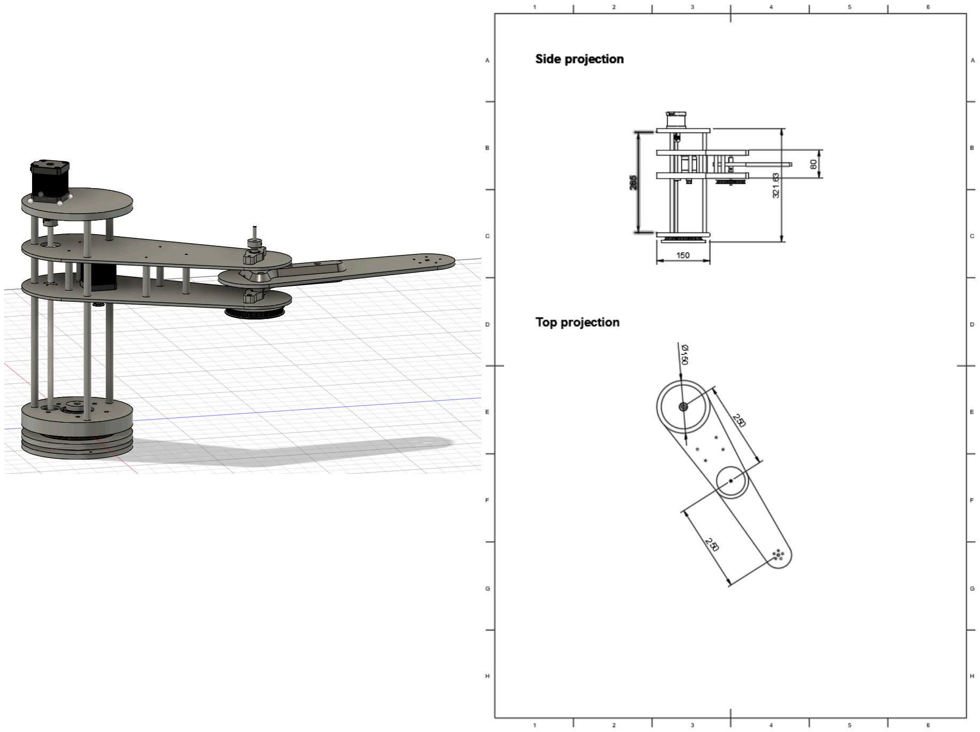
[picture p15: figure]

Details of the main arm + forearm
- The main arm
will be composed of two platforms. Both platforms will be cut out of MDF and held together with 3d printed pillars that will screw on each side with m3 screws.
- Top main arm platform
- 4mm MDF
- Bottom main arm platform
- 4mm MDF plates glued together with holes for the t8 lead nut and the nema 17 motors

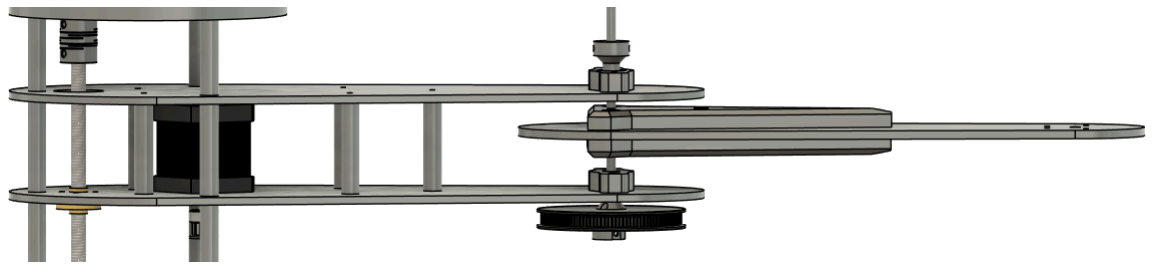
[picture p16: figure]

- The forearm
It will only be a single plate of 4mm thick MDF. It will have a 3d printed clamping mechanism attached on the bottom and the top part it will allow for the forearm to be clamped tight on the 5mm axle. The forearm will also have 4 m3 screw holes to have the gripper attached to it.

Different degree of freedom and linked mechanical parts
Rotation of the arm.
The rotation is induced by a nema 17 motor that will stay in the arm base.
- To ensure smooth gliding and side forces.
- We will use a flat axial bearing at the bottom so the whole assembly weight will sit on top of it

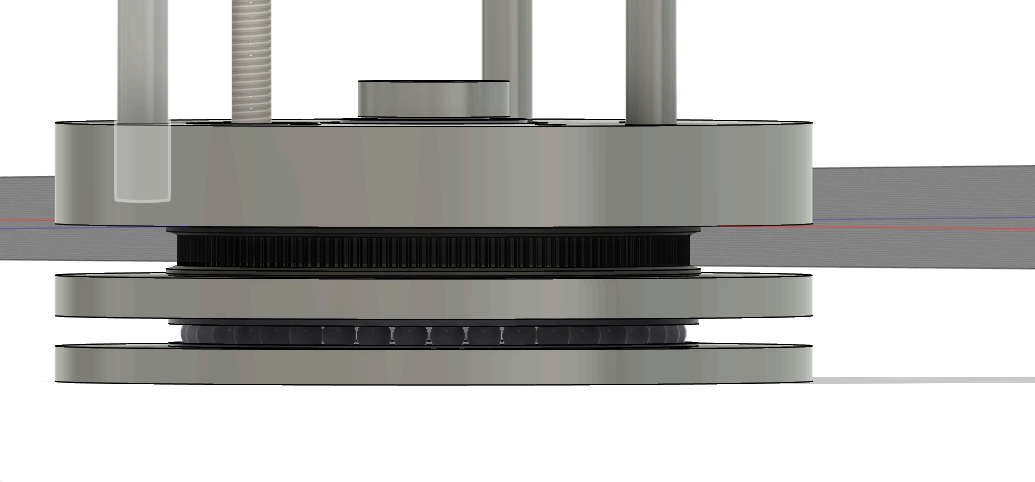
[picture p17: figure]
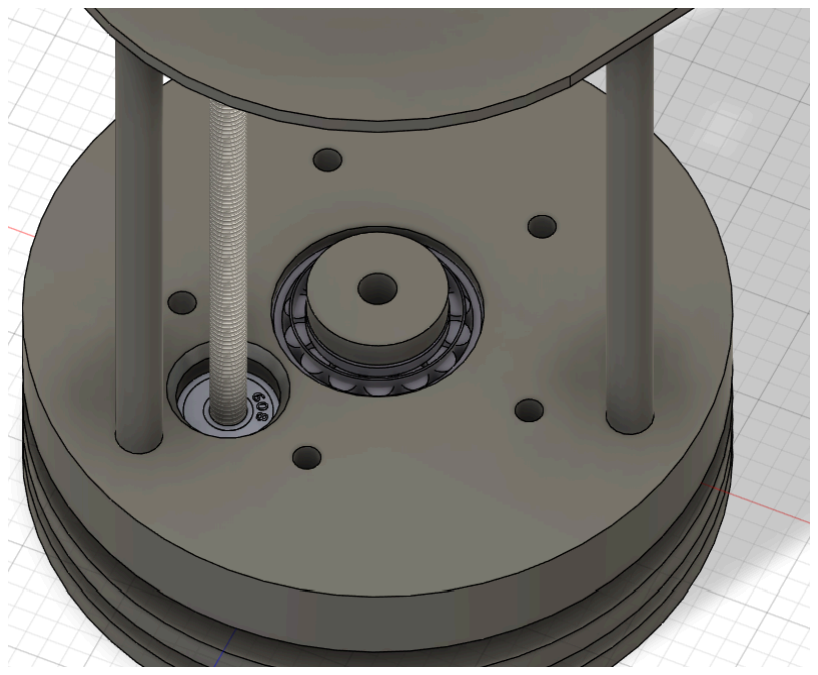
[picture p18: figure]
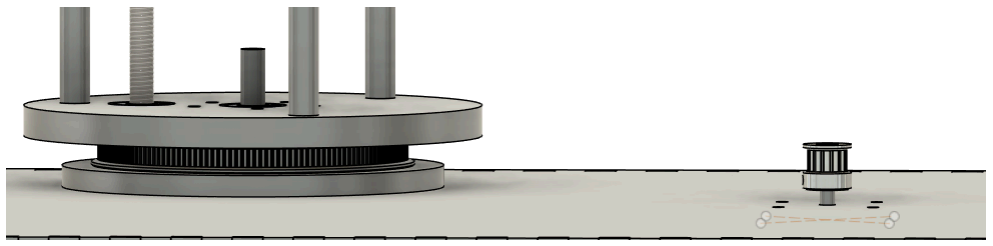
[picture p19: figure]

- and a conical bearing on top
- Both bearing will be tightened together using a m8 screw

Up down motion of the arm :
For the main arm to slide up and down a few components are involved in this motion
- The rails There will be 3 main slider rails that will resist any rotational movement of the main arm and provide some rigidity to the structure. For the rails we choose to go with some aluminium rods to stay as light as possible. The rails will be held to the base and to the top platform by clamping.
- Lead screw + lead nut + nema 17 The upward and downward motion of the main arm will be produced by a nema 17 stepper coupled to a t8 lead screw.
The lead nut will be attached to the main arm. Note that the lead screw will be supported by 2 608 bearings, one at the base, and on the upper platform of the main arm. The nema 17 will sit on the top platform and be directly coupled with a m8 to m5 shaft coupler.

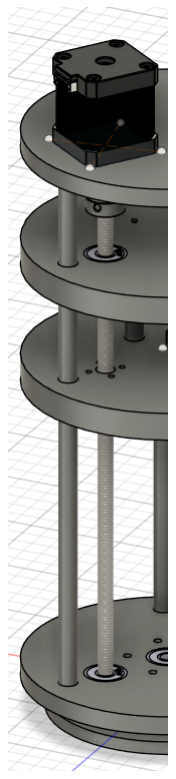
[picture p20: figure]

Forearm joint rotation :
The forearm rotation is induced in the same way as the rotation of the base. By a nema 17 that sits directly on the main arm it will drive a pulley connected to another bigger pulley which is also connected to a m5 shaft where the forearm is clamped to it. At the joint there are 2 625 bearings to support the m5 shaft for it to rotate smoothly. We decided to go with smaller bearings to reduce the weight.

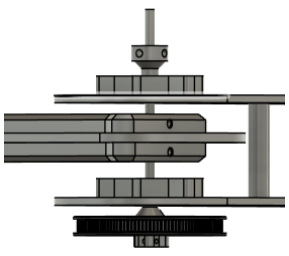
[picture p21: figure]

### The Gripper

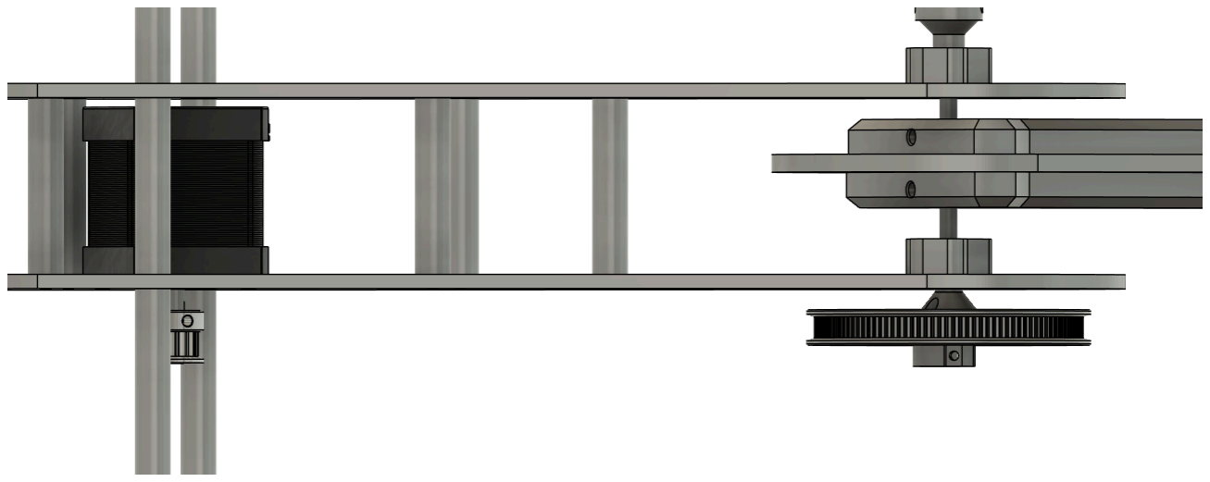
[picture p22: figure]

Two gripper concepts were explored before settling on the current design. The first used 4 gears driving two opposing arms, and the second used 3 gears with a worm screw and 3 arms. Both relied on a rotational closing motion, which turned out to be the core problem: as the arms close by rotating inward, they sweep sideways and risk disturbing neighboring pawns on the chessboard. This made both concepts unsuitable regardless of how well the transmission worked.

The current design addresses this directly. It uses a single gear with a rack-and-pinion mechanism to drive two jaws in a purely linear clamping motion, eliminating any lateral sweep. This is both mechanically simpler and much better suited to the tight spatial constraints of the chessboard.

The outer housing was modeled using a loft, and the jaw geometry was refined using a loft with guide rails to improve shape continuity beyond an initial block-based draft.

Mechanism :

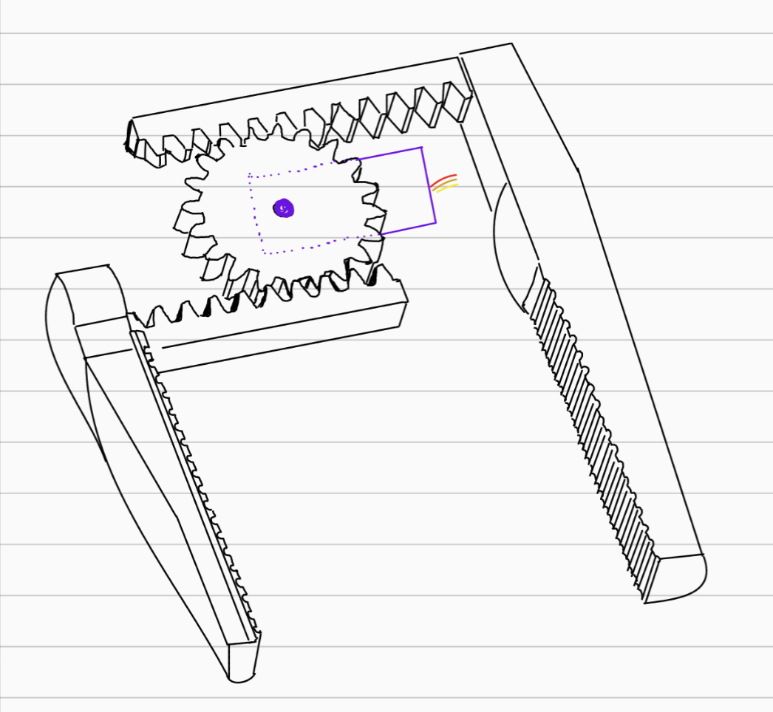
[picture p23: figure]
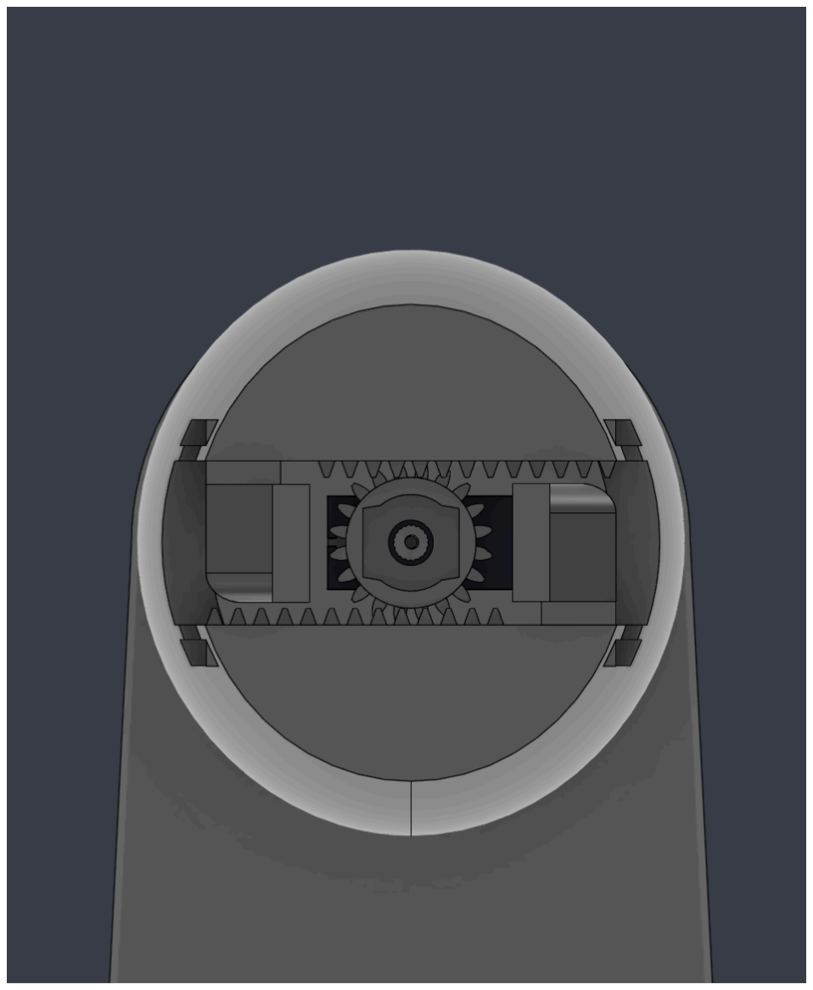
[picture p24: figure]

Mechanism | Bottom view

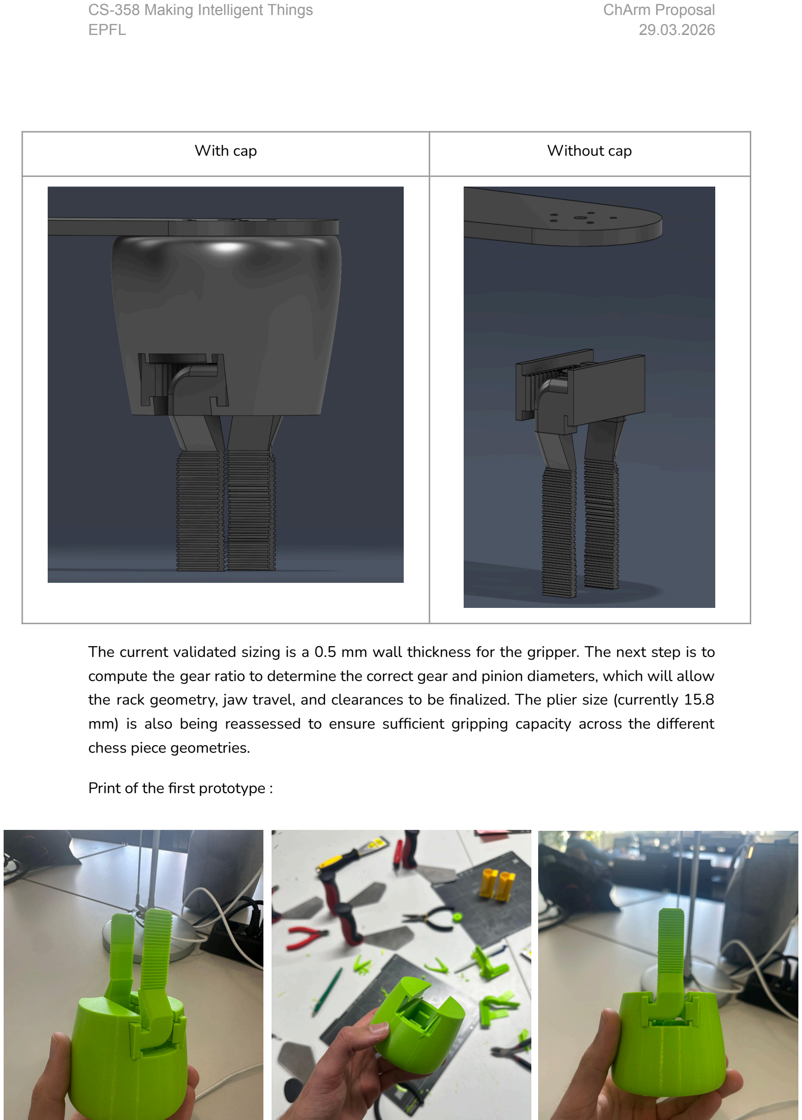
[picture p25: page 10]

With cap | Without cap

The current validated sizing is a 0.5 mm wall thickness for the gripper. The next step is to compute the gear ratio to determine the correct gear and pinion diameters, which will allow the rack geometry, jaw travel, and clearances to be finalized. The plier size (currently 15.8 mm) is also being reassessed to ensure sufficient gripping capacity across the different chess piece geometries.

Print of the first prototype :

## Software

Our primary objective for Milestone 1 is to hardcode the robotic arm's movements to ensure it can reliably grab and relocate objects. By implementing Inverse Kinematics, we will compute the required joint angles and linear actuator positions for a given XY target and height for the arm to follow the most efficient path to any target on the board.

For Milestone 2, the focus shifts to vision and calibration. We will identify square occupancy, piece color, and the board's boundaries through manual camera calibration to help accurately recognise each square, ensuring the movement detection and robot positioning is more precise. Using OpenCV, we will use HSV Color Space conversion to detect pieces. Unlike standard RGB, HSV is highly resistant to shadows, and allows us to count "black" or "white" pixels in each square to detect the color of pieces. To maximize contrast, we will use a rose and green chessboard, which ensures that the black and white pieces stand out clearly against the background during HSV filtering.

Milestone 3 represents the "intelligence" phase of the system. The program will detect movement by analyzing the difference in square occupancy between two distinct states. This will be managed by a physical button: the user presses it before and after their turn to capture the current frame of the board, allowing the system to identify the move made. We will integrate the Stockfish engine to analyze the position and generate the robot's counter-moves. To manage this data, we will use the python-chess library to store game states, validate move legality, and maintain a complete history of the match. Finally, when the robot discards an opponent’s piece, the robot will discard it in a designated area coded in the program. The main program will have the animated chessboard with all the pieces of the last captured frame with all the the pieces on the correct space of the captured frame, the main will also have displayed the camera feed with along with the grid lines for each square.

## Electronics

### Power distribution

A 12V, 5A DC power supply is needed to power the stepper motors. Starting from the power supply, it is connected to the CNC Shield and the buck converter in series. All components share a common ground.
The CNC Shield provides 12V to the three NEMA 17 stepper-motors through the 3 A4988 motor drivers. This has a peak draw of 2.5A.
The buck converter converts the 12V to 5V to power the ESP32-Cam (500mA when using wifi or flash), the 1 SG90 Servo (650mA), The Adafruit RGB LCD Shield Rev B1 (100mA)

and the Arduino Mega 2560 Rev3 (100mA) in parallel. The circuit has a potential 1.35A peak current draw, potentially more.

### Arm motors

Our SCARA Robot arm has 3 axis of movement:
- Z axis, moving the arm up and down on the pillar
- First circular movement around the pillar
- 2nd circular movement at the end of the first arm.
These axes are made possible by 3 NEMA 17 stepper motors connected through 4988 motor drivers. The Arduino Mega controls the steppers via STEP and DIR signals to the CNC Shield (pins 22-27).
We add 2 limit switches per axis to detect whether we hit the minimum or maximum limit. We can use the provided limit switch pins on the CNC shield that map back to pins 9, 10 and 11 on the Arduino mega.

### Grabber servo

We use a SG90 servo motor to control the closing and opening of our arm’s hand. It is powered after the buck converter with 5V and controlled with the Arduino Mega via PWM signal (pin 8).

### Vision

To see and analyse the chess board, we use an ESP32-Cam positioned above the chess board. It is powered with 5V after the buck converter and sends signals to the Arduino Mega via its GPIO 1 and GPIO 3 serial pins (TX and RX, respectively) to the Arduino’s RX0 and TX0 pins (pins 0 and 1). The built-in LED/Flash is connected via GPIO 4 to pin 2 on the arduino.

### Inputs

To input settings and tell the arm it is its turn, we use an Adafruit RGB LCD Shield Rev B1. It is powered with 5V after the buck converter and sends signals to the Arduino Mega’s SDA and SCL pins (pins 20 and 21).

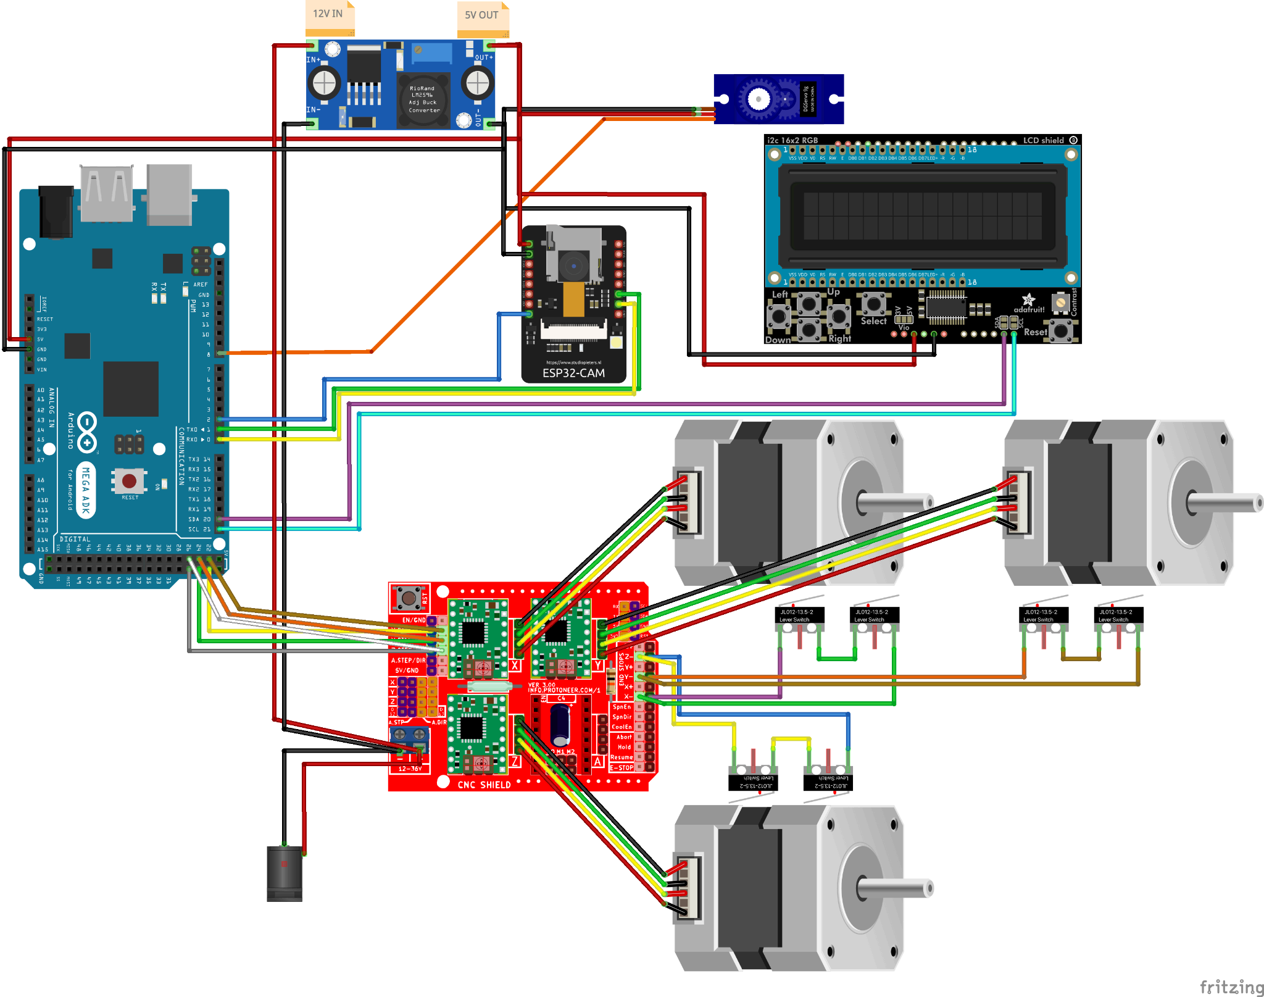
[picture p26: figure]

Electronic diagram

# Milestones

## Milestone 1

The objective of Milestone 1 is to develop a functional SCARA robotic arm capable of autonomously picking up and relocating chess pieces without relying on computer vision. At this stage, the focus is on the mechanical assembly and low-level control of the robot, the arm must be able to execute reliable movements, actuate the gripper, and place an object at a specified target location. The motion will initially be hardcoded, and inverse kinematics will be implemented to compute the required joint rotations and vertical displacement for a given board position. This milestone validates that the robot can physically perform the core pick-and-place task with sufficient precision and repeatability.

## Milestone 2

The goal of Milestone 2 is to equip the system with the ability to perceive and interpret the chessboard state, prototype the chess board and the pieces. This includes integrating the overhead camera, calibrating its position with respect to the board, and detecting the limits of the board as well as the occupancy of each square. The system will also distinguish between black and white pieces using image processing techniques in OpenCV, with HSV colour space used to improve robustness against lighting variations and shadows. At the end of this milestone, the robot should be able to identify whether a specific square is occupied, determine the colour of the occupying piece, and accurately map visual information to physical board coordinates.

## Milestone 3

Milestone 3 represents the intelligent layer of the project, where the system becomes capable of playing a full chess game against a human user. The program will detect the player’s move by comparing two captured board states, taken before and after the user’s turn, for example through a button-triggered update. The recognised move will then be stored and validated using a chess-state management library such as python-chess, while Stockfish will be used to compute the robot’s counter-move. The robotic arm will then execute this move physically on the board, including moving captured pieces to a designated discard area. By the end of this milestone, the full pipeline, from board-state recognition to chess-engine decision-making and physical move execution, will be operational.

# User Stories

### 1. CS-358 professor / future student teams

One important user group is the CS-358 professor and future student teams. For them, the main value of the project is not only the final demonstration but also its usefulness as a reusable learning platform.

Our SCARA arm should therefore be more than a one-time prototype. It should be documented and structured clearly enough that future teams can understand, reproduce, and improve it. Since we would like the project to move toward a chess-playing robotic system, it is important that the platform remains modular and easy to extend.

To support this, the project should provide a clear GitHub repository with the control code, CAD files, wiring diagrams, concise setup instructions and a simple Bill of Materials (BOM). The project will be especially valuable if future teams can build on it to improve motion control, piece handling, or chess-related interaction.

### 2. Chess player / interactive user

Another key user group is the chess player interacting with the robot. For this user, the most important aspect is that the interaction feels clear, accurate, and engaging.

The user should be able to make a move on the board and easily understand how the robotic arm responds. Even in an early version, the system should already demonstrate the idea of a robot physically participating in a chess game.

This means the arm should move pieces in a controlled, visible, and safe way, while making the turn-taking process easy to follow. The project succeeds for this user if the interaction feels intuitive and the robot is perceived as an active part of the game rather than just a mechanical demo.

### 3. EPFL IC faculty / outreach staff

A third important user group is the EPFL IC faculty and outreach staff, who may use the project during presentations or public events. For them, the priority is reliability, safety, and ease of use.

From this perspective, the SCARA arm should be easy to set up, simple to operate, and robust enough to run repeated demonstrations without frequent intervention. A chess-related demo is especially suitable because it is visually clear and easy for visitors to understand.

The project will be successful for this user group if it can be set up quickly, run reliably in public, and serve as an engaging example of robotics at EPFL.

# Known and Useful Resources

- The electronic components choices and electronic circuit was inspired by the 2025 Container Terminal 1 project done previously in CS-358. URL : https://github.com/epfl-cs358/2025fa-terminal1
- The software part of the project was mostly inspired by the "Chess Playing Robot Arm That Will Beat You!" from hackster.io, and also by the YouTube video: Building a Chess Robot Using the AR4 MK3 and Python. In particular, this is where we found the idea of capturing the current frame of the board and using the Stockfish library. URL:
https://www.hackster.io/ricpd/chess-playing-robot-arm-that-will-beat-you-678035,https://www.youtube.com/watch?v=qwZDZwg1g9o
- The library we will use for the computer vision part is OpenCV (https://opencv.org).
- The chess engine will be provided by Stockfish (https://stockfishchess.org).
- To store game states, validate move legality, and maintain a complete history of the match, we will use python-chess (https://python-chess.readthedocs.io/en/latest/)

# Bill of Materials

Part Name | Numb er Part | Part Price | Total Price | Link | Justification
Tapered roller bearing LM11949 | 1 | 1 | 5 | view (https://www.kugellager-express.de/tapered-roller-bearing-lm11949-lm11910-19-05x45-237x15-494-mm) | conical bearing used for the base rotation

Axial ball bearing

51116 | 1 | 1 | 9 | view (https://www.kugellager-express.de/axial-deep-groove-ball-bearing-51116-80x105x19-mm) | axial bearing used for the base rotation
nema 17 pulley (GT2) | 2 | 4 | 8 | view (https://www.bastelgarage.ch/poulie-z20-gt2-6-avec-alesage-de-5mm-et-siege-de-16mm?search=poulie) | used on the motor shaft for the base and the arm joint
608 bearing | 2 | 1 | 2 | mechanical workshop | t8 lead screw support
625 bearing | 2 | 1 | 2 | view (https://www.conrad.ch/fr/p/ubc-bearing-625-2z-roulement-a-billes-radial-o-de-percage-5-mm-o-exterieur-16-mm-regime-max-36000-tr-min-198818.html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) | for arm joint rotation
GT2 closed timing belt 640mm | 2 | 6,9 | 13,8 | view (https://www.bastelgarage.ch/640mm-gt2-belt-6mm-closed?search=gt2%20belt)
lead screw t8x2 | 1 | 21 | 21 | view (https://www.3djake.ch/de-CH/twotrees/t8-gewindespindel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) | for upward and downward movement of the arm
lead screw t8 nut (2mm pitch) | 1 | 1 | 1 | view (https://www.bastelgarage.ch/tr8-trapezoidal-nut-brass-pitch-8mm) | link t8 screw
5mm to 8mm coupler | 1 | 4 | 4 | view (https://www.bastelgarage.ch/tr8-trapez-mutter-messing-pitch-2mm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) | link t8 screw to nema 17 motor shaft
Aluminium rod | 1 | 5 | 5 | mechanical workshop | sliding rails for the arm
NEMA 17 (5 CM one) | 3 | 10 | 30 | view (https://www.conrad.ch/fr/p/moteur-pas-a-pas-joy-it-nema-17-01-0-4-nm-1-68-a-diametre-de-l-arbre-5-mm-1-pc-s-1597325.html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) | used for different rotations/movement of the arm
Connecter Cables for the NEMA 17 Steppers | 3 | 2,9 | 8,7 | view (https://www.bastelgarage.ch/6p-ph2-0-to-4p-xh2-54-stepper-motor-cable-1m-nema17) | to connect the motors to the circuit
A4988 driver | 3 | 3,9 | 11,7 | view (https://www.bastelgarage.ch/a4988-stepper-motor-driver-module) | to drive the nema 17 motors
CNC shield | 1 | 3 | 3 | view (https://www.conrad.ch/de/p/joy-it-controllerboard-cnc-fuer-arduino-uno-motortreiber-1646889.html?WT.srch=1) | to drive the 3 axis movement
AIThinker ESP32-CAM | 1 | 4 | 4 | course stock | camera to implement computer vision

Arduino Mega

2560 | 1 | 14 | 14 | course stock | microprocessor signaling all components of the circuit
Servo MG90S | 1 | 7,9 | 7,9 | view (https://www.bastelgarage.ch/towerpro-micro-servo-mg90s-with-metal-gear) | motor for closing and opening of the gripper
Adafruit RGB LCD Shield Rev B1 | 1 | 20,14 | 20,14 | view (https://www.reichelt.com/ch/en/shop/product/arduino_lcd_shield_kit_16x2_blue-and-white_display-159967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) | display and buttons to interact with the arm

# Risk Assessment and Potential Challenges

## Mechanical

### ARM rigidity

- Issue: The arm structure may have too much flex and so not as precise as wanted.
- Mitigation:
- Add rigidity pillars and attachment that go the whole way of the arm / forearm
- Have a very light chess set and gripping system

### Up and down motion stutter

- Issue: the arm sliding on the 3 guide rails may result in friction that will cause some unwanted movements
- Mitigation:
- Add some “pallier lisse”(available in the mechanical workshop) to the MDF structure so it will slide better

### Arm reach

- Issue: even though calculated the arm may struggle to precisely reach some chess pieces
- Mitigation:
- Adapt the chess board size and placement

LM2596 buck
converter
1 | 6,95 | 6,95 | view (https://www.coolbe.ch/de/products/65378647de7fd501789f9cba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) | to convert 12V to 5V to power the components

DC 12V, 5A power
supply
1 | 9,67 | 9,67 | view (https://www.coolbe.ch/de/products/5d380ac98b451301016177d3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) | to power the whole arm

DC Barrel Power
Jack
1 | 1,18 | 1,18 | view (https://www.distrelec.ch/en/dc-power-connector-socket-right-angle-x6-4xmm-pack-of-pieces-wuerth-elektronik-694106301002/p/30429066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) | to connect the power supply to the circuit

Gaine cable
management
1 | 2,3 | 2,3 | view (https://www.conrad.ch/fr/p/quadrios-25ca532-gaine-thermoretractable-en-tissu-noir-6-mm-3-mm-taux-de-retreint-2-1-marchandise-vendue-au-metre-3450040.html) | cable management

KW11-3Z limit
switches
6 | 1,295 | 8 | view (https://www.fruugoschweiz.com/10-pieces-kw11-3z-5a-250v-straight-lever-type-micro-limit-switch-spdt-3-pin-momentary-hinge-roller-lever-micro-switch-black/p-44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) | may be used to restrict the different movement
Total | 176,34

### Gripper

- Issue: The gripper may fail to generate enough force to securely hold and lift some chess pieces.
- Mitigation:
- Add silicone or rubber pads to the inner jaw surfaces to increase friction.
- Size the pinion radius and jaw geometry so that the required gripping force remains below the servo torque limit with a safety factor.
- Test the gripper using the heaviest chess piece early in prototyping.
- Issue: A piece may initially be gripped correctly but slip while the arm is moving.
- Mitigation:
- Use smoother motion profiles during lifting, transport and testing.
- Limit acceleration while carrying a piece.

## Electronics

### ESP32-CAM Power Instability

- Issue: The ESP32-CAM draws short bursts of high current when the camera or Wi-Fi module is active, which can reset the board if the 5 V rail isn’t stable.
- Mitigation:
- Keep the 5 V line short and thick.
- Use a low-ESR capacitor (≥470 μF) across the ESP32’s 5 V and GND pins.
- Test Wi-Fi connection while motors are running to check for power dips.

### Insufficient current to motors

- Issue: Moving the arm using all three stepper motors at the same time might draw too much power and prevent the motors from moving correctly
- Mitigation
- Testing how many motors can run at once
- Making it so only one motor can move at a time

### Buck converter bottleneck

- Issue: the 5 components after the buck converter have a peak current draw of 1.35A, potentially more. The buck converter could overheat.
- Mitigation
- Monitoring and testing the circuit for power spikes
- Attaching a heat sink to the buck converter

## Software

### ESP32-CAM Resolution Quality

- Issue: We plan to use the camera to keep track of chess pieces to give instruction to which one the robotic arm needs to move. Low camera quality can make identification considerably harder
- Mitigation:
- Using high contrast colors between chess pieces and the chess board (making the chess board green and pink).
- Test using different lighting conditions or positions of the camera.
- We could use the camera’s flash when capturing each frame to improve image quality and visibility.
- As a last resort, we can add a support to hold a phone above the board, using its flash to provide additional lighting, or even use the phone’s camera.

### Special Rule Cases

- Issue: Handling castling moves can be challenging, as this is the only case where the robot does not perform a standard single-piece move. Additionally, the resulting board changes may appear unusual to the engine compared to typical moves.
- Mitigation:
- We will handle castling operations separately when the engine instructs the robot to perform such a move.
- Detection of castling moves performed by the opponent will also be treated as a special case and handled independently.

### Low Color Saturation

- Issue: The ESP32-CAM aggressively normalizes colors under indoor lighting, washing out colors into near-grey. This can make HSV detection unreliable.
- Mitigation:
- Disable the ESP32-CAM's Auto White Balance (AWB) in the Arduino firmware to prevent the camera from automatically normalizing colors, which would preserve the original saturation of the squares
- Use more saturated colors for the board squares
- Artificially boost the saturation channel in OpenCV before applying HSV thresholding

### Camera Distance and Field of View

- Issue: At the required 40cm mounting height for the robot arm, the printed squares only cover a small portion of the camera's field of view, making the individual squares too small for reliable color detection. Additionally, The camera occasionally detects background noise, shadows, or objects outside the target area, leading to incorrect identification.
- Mitigation:
- Zoom lens to fill the frame better at 40cm.
- Use Area Filtering to ignore detected shapes that are too small or too large to be valid pieces.

### Image Capture Latency (Lag)

- Issue: The ESP32-CAM has a transmission delay where the captured image is sometimes a "stale frame" from a previous cycle.
- Mitigation:
- Add a buffer flushing routine in the code to ensure the system always processes the most recent frame.

# Organization

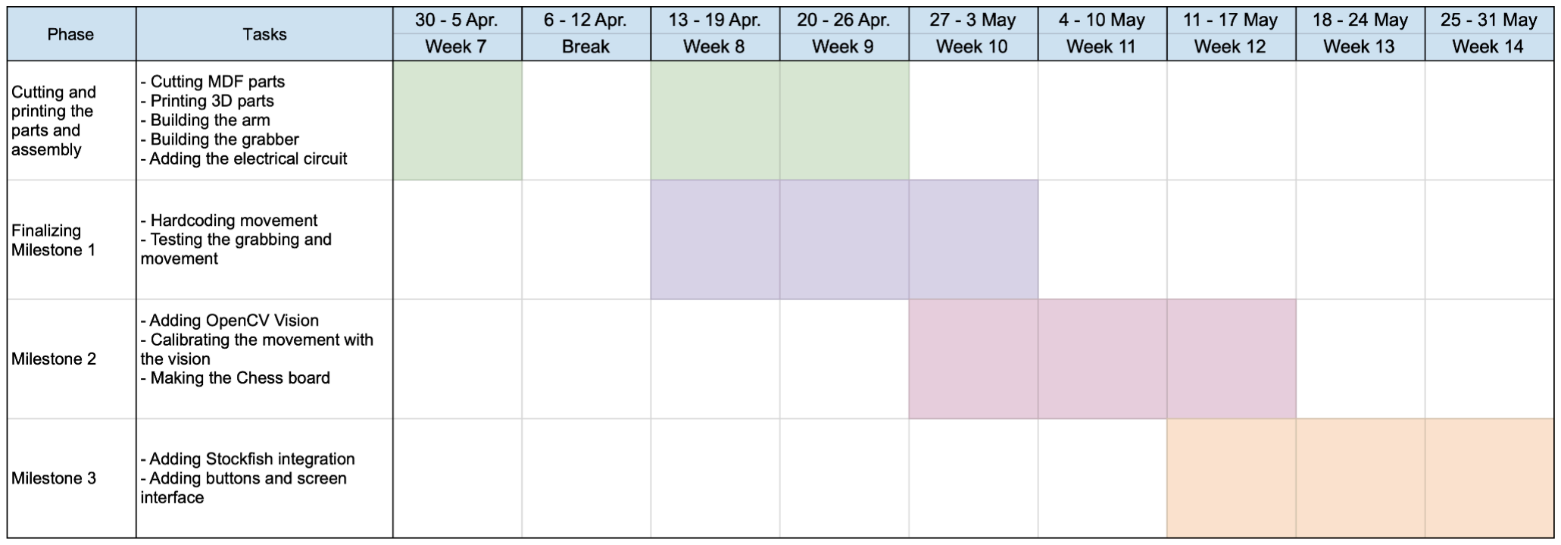
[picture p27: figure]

### Making and assembling the parts

This phase is about making or acquiring all the necessary parts for the project build. This entails laser cutting all parts from MDF (arm, box, …) and 3D printing the grabber and gears. Next, a first version of the arm will be assembled with the electrical so we design the software for it. We will be coming back and modifying parts throughout the project when necessary.
Responsibilities:
Mechanical build : Allan
- CAD of the whole arm assembly
- Prototyping of the arm assembly
Gripper : Fazil, Nika
- Design chess pieces
- Continue working on the CAD of the new gripper
- Adjust the dimensions of the gripper and gears accordingly Electrical : Sipke
- Assemble the electrical circuit
- Test the currents
- Sketch out the future I/O for the software

### Finalizing Milestone 1

While the physical part of milestone 1 is being completed, part of the team can write the software. This means hardcoding the movement of the arm and grabber. When both the mechanical and software parts are put together, we can test whether the arm works as intended.
Responsibilities
Software : Tamara, Haobin, Jiayi
- Provide an interface to control the arm
- Calibrate the inverse kinematics

### Milestone 2 & 3

In these phases, the team can alternate implementing the vision part of the software while also making a chess board to play on. Together, we have to test if the arm is able to differentiate between pieces, locate them and move accordingly. Then, we implement the “thinking” with stockfish so that we can play against it.

# Appendix

## Summary of risks table

Risk | Impact | Likelihood | Mitigation / Early Prototype
Arm Rigidity and Flex | High | Medium | Reinforce the arm and forearm with rigidity pillars and full-length supports. Use lightweight but rigid materials, and keep the chess set and gripping system as light as possible.
Vertical Motion Stutter | Medium | Medium | Reduce friction on the three guide rails by adding smooth bushings (paliers lisses) to the MDF support. Test repeated up-and-down motion early in the prototyping phase.
Arm Reach and Positioning Limits | High | Medium | Validate the real reachable workspace with an early prototype. If some squares are difficult to reach precisely, adapt the chessboard size and placement accordingly.
ESP32-CAM Power Instability | Medium | Low | Keep the 5 V line short and thick, and add a low-ESR capacitor (≥470 μF) across the ESP32-CAM 5 V and GND pins. Test Wi-Fi and camera operation while motors are running.
Insufficient Current for Motors | High | Medium | Test how many motors can reliably operate at the same time. If necessary, limit the control strategy so that only one motor moves at a time.
Buck Converter Bottleneck | Medium | Medium | Monitor the circuit for current spikes and test the converter under sustained load. Add a heat sink if overheating becomes an issue.
ESP32-CAM Resolution / Image | High | Medium | Use strong visual contrast between the chessboard and the pieces. Test

Quality | | | different lighting conditions and camera positions, and use the onboard flash if necessary.
Low Color Saturation | High | High | Disable Auto White Balance (AWB) in the ESP32-CAM firmware, use more saturated board colors, and boost the saturation channel in OpenCV before HSV thresholding.
Camera Distance / Field of View | High | Medium | Improve framing through better camera placement or a zoom lens. Use area filtering to reject shapes that are too small or too large to correspond to valid pieces.
Image Capture Latency (Stale Frames) | Medium | High | Add a buffer-flushing routine so that the system always processes the newest available frame. Validate response time through repeated image capture tests.
Special Rule Cases | Medium | Medium | Handle castling as a dedicated software case, both when it is executed by the robot and when it is detected from the opponent’s move. Validate it separately from standard moves.
Gripper force / slipping | High | Medium | Add high-friction pads, size the pinion and jaws with a safety factor, and test on the heaviest piece under realistic motion.

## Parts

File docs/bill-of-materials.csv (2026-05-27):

Part Name | Amount
16x2 1602A LCD Display | 1
17HS4401 Stepper motors | 3
2.1mm DC Barrel Jack | 1
220Ω Resistor | 4
5mm to 8mm coupler | 1
608 bearing | 2
625 bearing | 2
A4988 Motor Drivers | 3
AIThinker ESP32-CAM | 1
Aluminium rod | 1
Arduino Mega 2560 | 1
Axial ball bearing 51116 | 1
CNC shield | 1
Connecter Cables for the NEMA 17 Steppers | 3
DC 12V-5A power supply | 1
ESP32 - D | 1
Gaine cable management | 1
GT2 closed timing belt 640mm | 2
KW11-3Z limit switches | 4
KY-040 Rotary encoder | 1
lead screw t8 nut (2mm pitch) | 1
lead screw t8x2 | 1
LM2596 Buck Converter | 1
Nema 17 pulley (GT2) | 2
Potentiometer | 1
Servo MG90S | 1
Tapered roller bearing LM11949 | 1
Wago 221-415 | 2

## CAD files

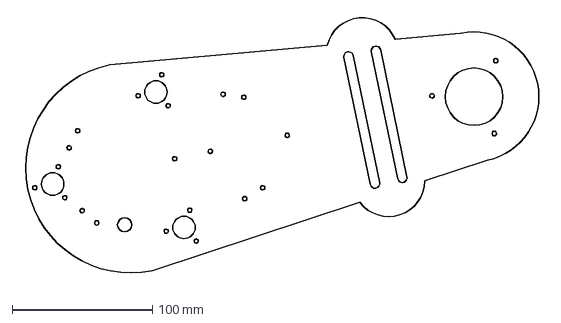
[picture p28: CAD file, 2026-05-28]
docs/CAD/dxf/arm/main_arm_plateform_top.dxf
377.1 x 189.8 mm

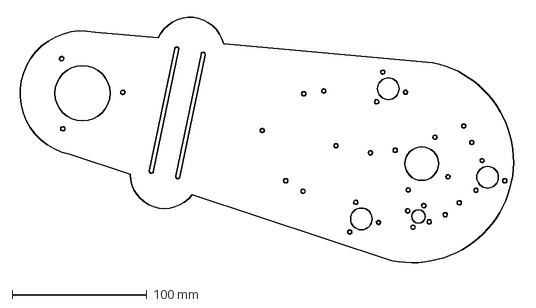
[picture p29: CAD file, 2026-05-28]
docs/CAD/dxf/arm/main_arm_plateform_bottom.dxf
373.5 x 186.9 mm

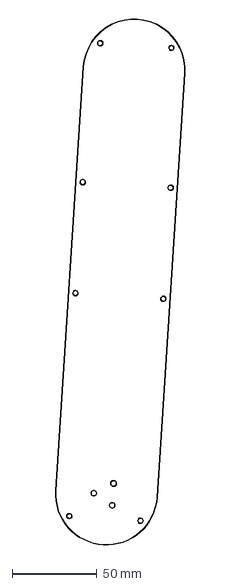
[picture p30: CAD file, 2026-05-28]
docs/CAD/dxf/arm/foerarm_plateform_top.dxf
78.0 x 313.0 mm

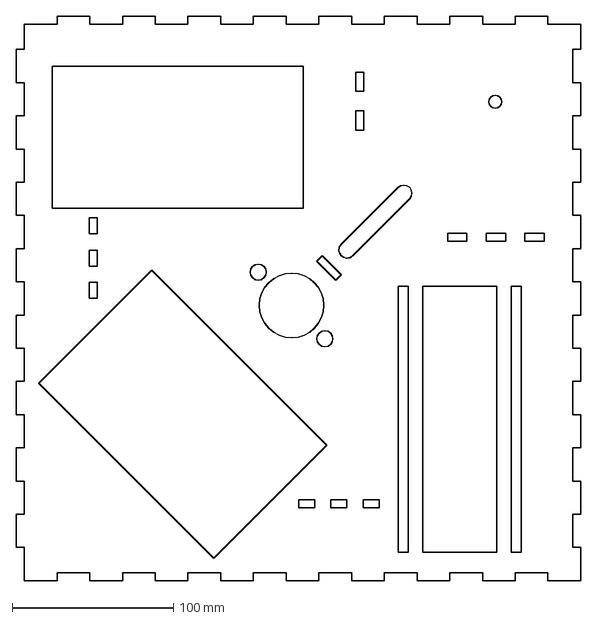
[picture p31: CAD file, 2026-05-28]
docs/CAD/dxf/box/top_plateform.dxf
350.0 x 350.0 mm

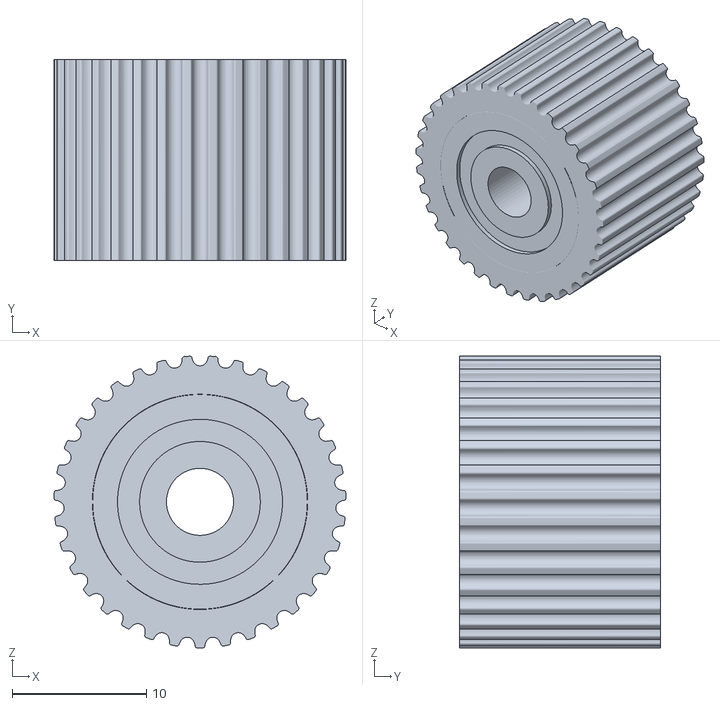
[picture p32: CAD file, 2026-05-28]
docs/CAD/stl/tensionner_pulley.stl
21.8 x 15.0 x 21.7

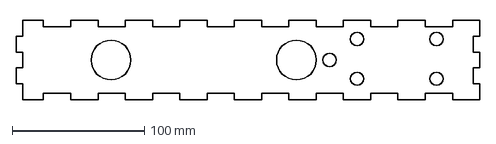
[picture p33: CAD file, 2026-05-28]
docs/CAD/dxf/box/side1.dxf
350.0 x 60.0 mm

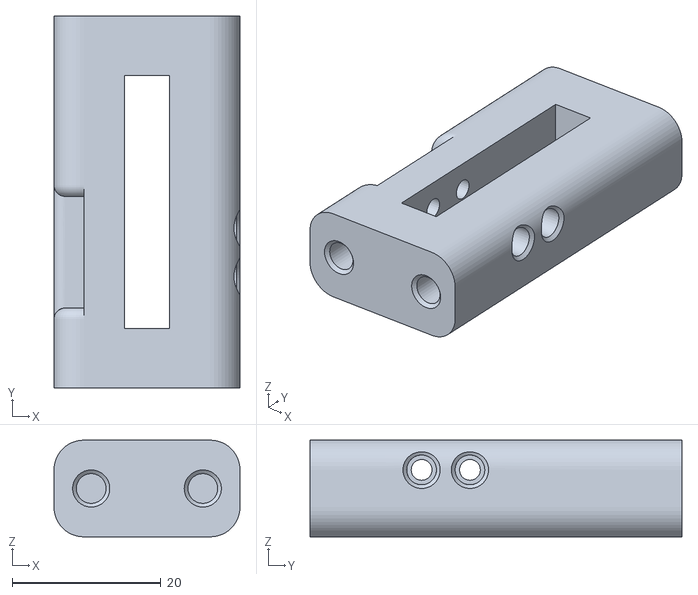
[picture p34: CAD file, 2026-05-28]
docs/CAD/stl/new_limit_switch_holder.stl
25.0 x 50.0 x 13.0

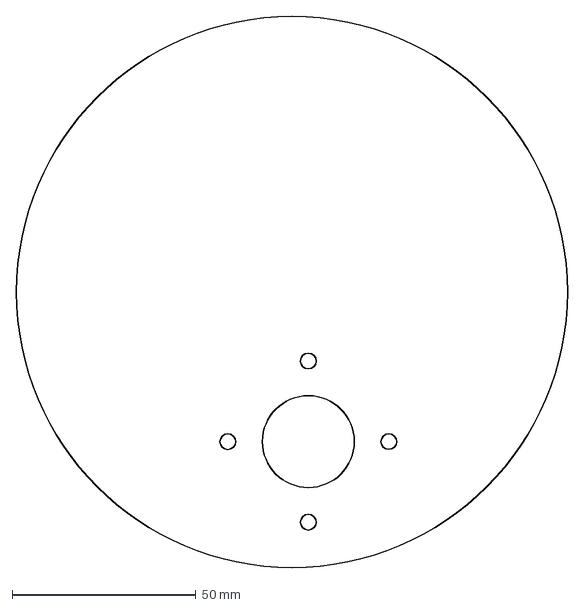
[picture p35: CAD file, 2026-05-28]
docs/CAD/dxf/arm/top_plateform_layer2.dxf
150.0 x 150.0 mm

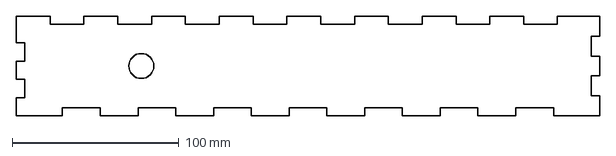
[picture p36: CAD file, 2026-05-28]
docs/CAD/dxf/box/side3.dxf
350.0 x 60.0 mm

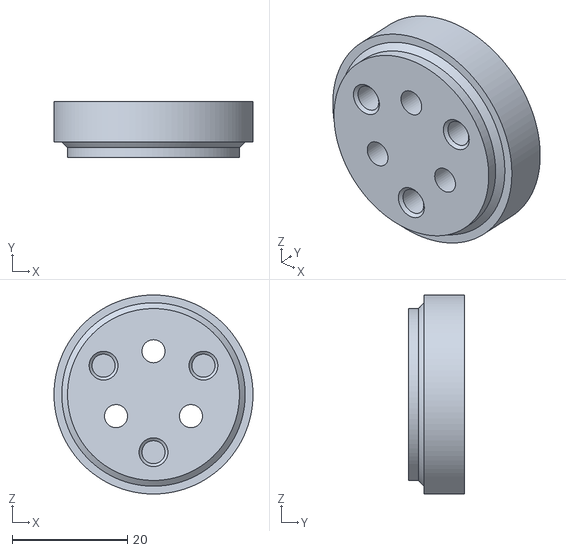
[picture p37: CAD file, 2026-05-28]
docs/CAD/stl/arm_bearing_hold.stl
34.5 x 9.70 x 34.5

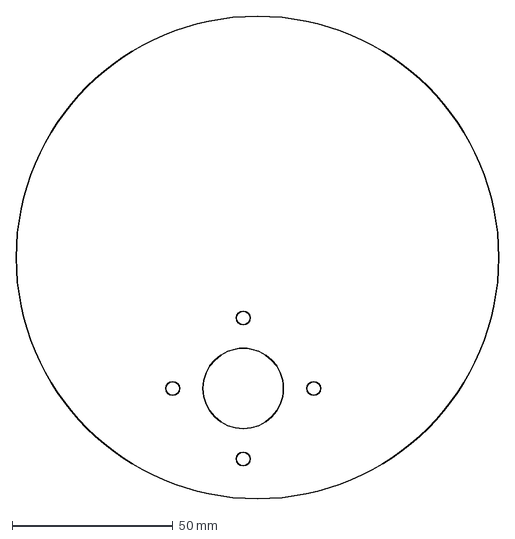
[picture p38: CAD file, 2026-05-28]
docs/CAD/dxf/arm/top_plateform_layer1.dxf
150.0 x 150.0 mm

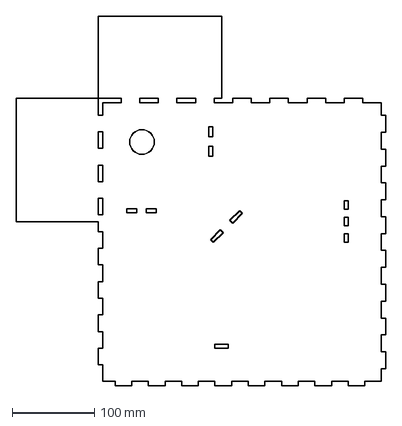
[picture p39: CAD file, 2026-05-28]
docs/CAD/dxf/box/bottom_plateform.dxf
450.0 x 450.0 mm

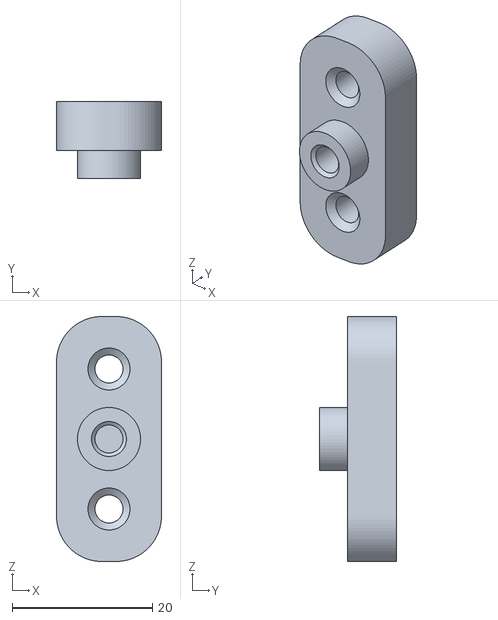
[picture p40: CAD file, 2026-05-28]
docs/CAD/stl/tensionner_base.stl
15.0 x 11.0 x 35.0

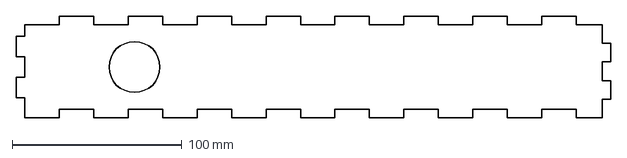
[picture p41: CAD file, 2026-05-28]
docs/CAD/dxf/box/side2.dxf
350.0 x 60.0 mm

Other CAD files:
docs/CAD/stl/top_bearing_mount.stl
docs/CAD/dxf/arm/forearm_plateform_bottom.dxf
docs/CAD/dxf/box/side4.dxf
docs/CAD/stl/tensionner_pulley_bearing_inserts.stl
docs/CAD/stl/base.stl
docs/CAD/stl/base_bearing_insert.stl
docs/CAD/stl/bearing_holder.stl
docs/CAD/stl/gt2_pulley_base.stl
docs/CAD/stl/limit_switch_holder_bottom.stl
docs/CAD/stl/linear_bearing_holder_half.stl
docs/CAD/stl/new_joint_gear.stl
docs/CAD/stl/new_limit_switch_holder_mirrored.stl

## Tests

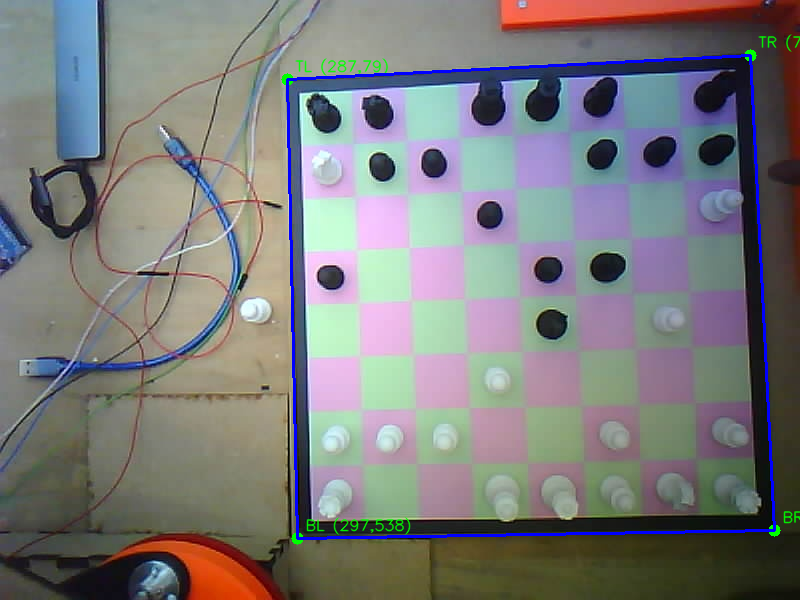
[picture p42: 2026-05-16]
python_code/e2e_debug/game_1_all_photos_main_piece_color_detector/photo_017_20260515_175254_874/photo_017_20260515_175254_874_after_player_calibration_1_points.png

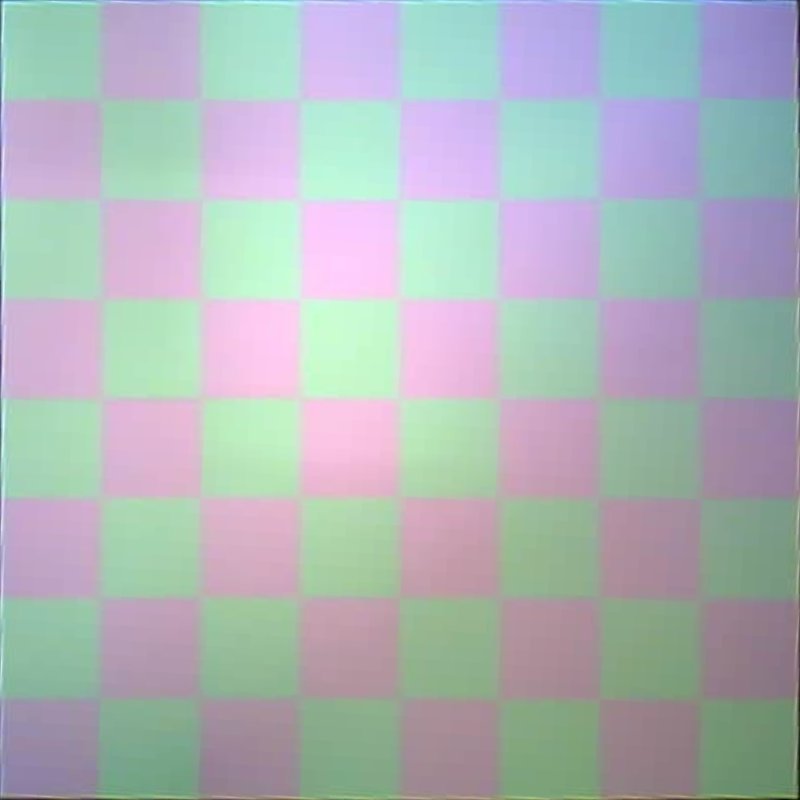
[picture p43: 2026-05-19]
python_code/webapp_snapshots/manual_calibration_2026_05_18T21_47_41_792/refined_warp.jpg

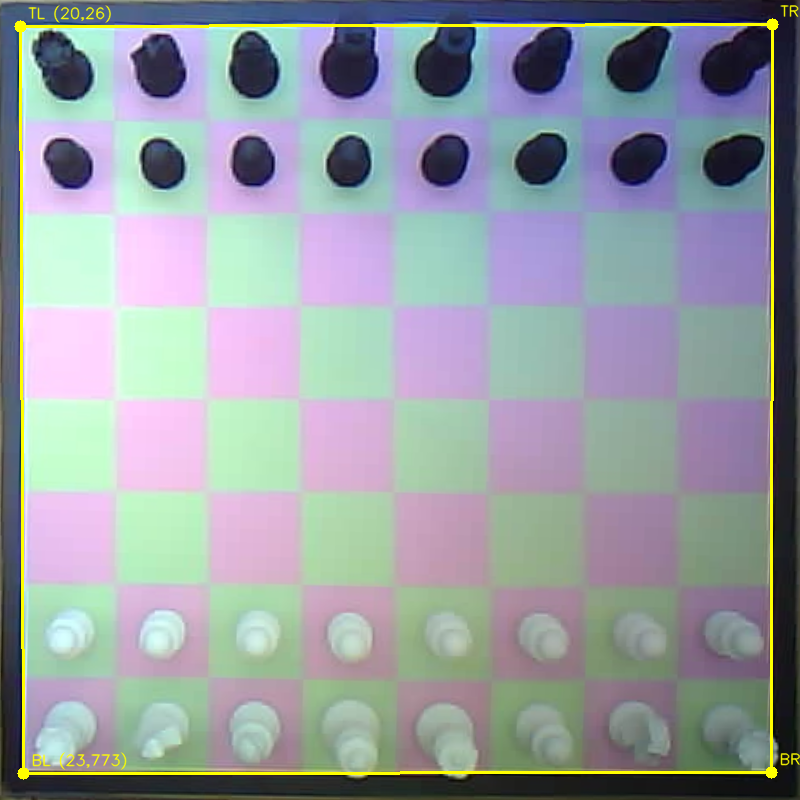
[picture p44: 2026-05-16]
python_code/e2e_debug/game_1_all_photos_main_piece_color_detector/photo_004_20260515_174603_200/photo_004_20260515_174603_200_after_player_calibration_2_points.png

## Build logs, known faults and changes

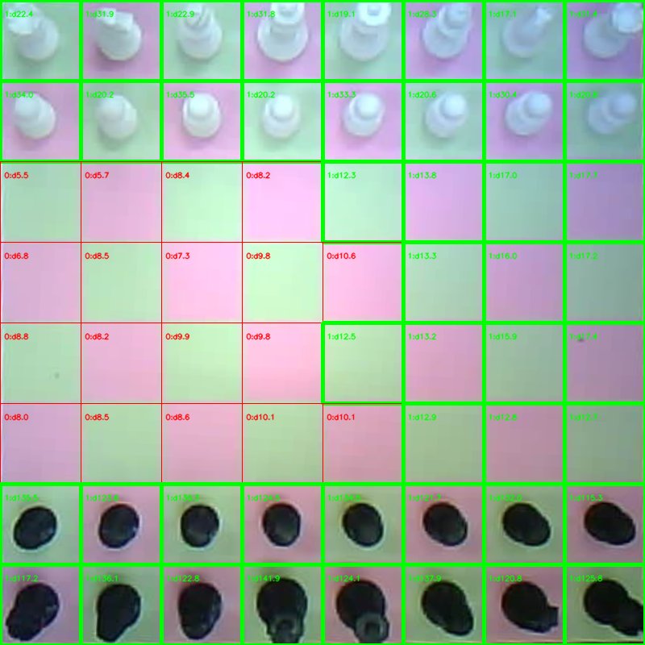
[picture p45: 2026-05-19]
python_code/webapp_snapshots/manual_calibration_2026_05_18T22_19_42_981/occupancy_debug.jpg

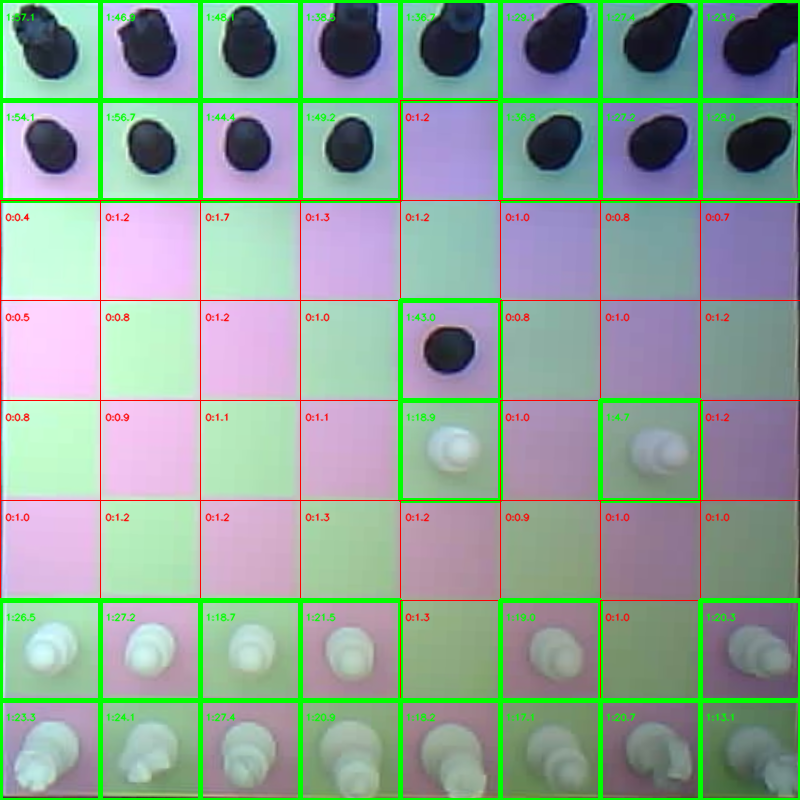
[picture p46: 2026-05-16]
python_code/e2e_debug/game_1_all_photos_main_piece_color_detector/photo_007_20260515_174620_359/photo_007_20260515_174620_359_after_player_occupancy_debug.png

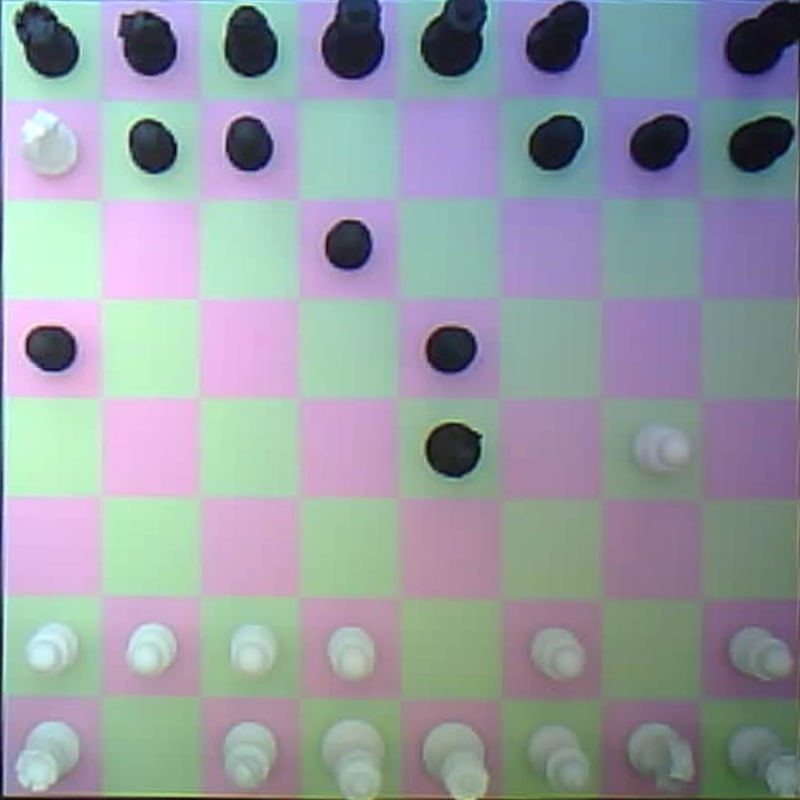
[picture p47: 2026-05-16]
python_code/e2e_debug/game_1_all_photos_main_piece_color_detector/photo_014_20260515_175226_749/photo_014_20260515_175226_749_after_player_refined_warp.png

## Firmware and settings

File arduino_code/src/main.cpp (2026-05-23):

#include <Arduino.h>
#include <EEPROM.h>
#include "hardware/src/pins.h"
#include "hardware/src/stepperXYZ.h"
#include "hardware/src/scaraJoint.h"
#include "hardware/src/leadScrew.h"
#include "hardware/src/scaraArm.h"
#include "hardware/src/config.h"
#include "hardware/src/gripper.h"
#include "hardware/src/limitSwitch.h"
#include "hardware/src/enableDriver.h"

StepperXYZ xStepper(X_STEP_IN1, X_DIR_IN1);
StepperXYZ yStepper(Y_STEP_IN1, Y_DIR_IN1);
StepperXYZ zStepper(Z_STEP_IN1, Z_DIR_IN1);

LimitSwitch j1Lim(X_LIMIT_PIN);
LimitSwitch j2Lim(Y_LIMIT_PIN);
LimitSwitch zLim(Z_LIMIT_BOTTOM_PIN);

ScaraJoint joint1(xStepper, STEPS_PER_REV, MICROSTEPS, GEAR_RATIO_J1, j1Lim, false); //base
ScaraJoint joint2(yStepper, STEPS_PER_REV, MICROSTEPS, GEAR_RATIO_J2, j2Lim, true);  //forearm
Gripper gripper(GRIPPER_PIN, OPEN_ANGLE, CLOSED_ANGLE);
LeadScrew leadScrew(zStepper, STEPS_PER_MM, Z_MAX_MM, zLim);

ScaraArm arm(joint1, joint2, leadScrew, gripper, LINK1_LENGTH, LINK2_LENGTH);

int stepCount = 0;
static String cmdBuffer = "";

// Cartesian jog mode: w/a/s/d move XY, u/j move Z. Toggle with `cm`.
static bool controllerMode  = false;
static bool calibrationMode = false;
static const float JOG_XY_MM     = 3.0f;
static const float JOG_Z_MM      = 1.5f;
static const float CAL_JOG_XY_MM = 1.0f;
static const float CAL_JOG_Z_MM  = 0.5f;

// ── Board calibration ────────────────────────────────────────────────────────
// 3-corner vector decomposition: capture arm (x,y) at H1, A1, H8.
// Every square is then: P = h1 + fileFromH*vFile + rankIdx*vRank
// Z is NOT part of board calibration — user picks travel height manually.
static bool  h1Calibrated = false, a1Calibrated = false, h8Calibrated = false;
static float h1X = 0, h1Y = 0;
static float a1X = 0, a1Y = 0;
static float h8X = 0, h8Y = 0;
static bool  trashCalibrated = false;
static float trashX = 0, trashY = 0;

static bool boardCalibrated() { return h1Calibrated && a1Calibrated && h8Calibrated; }
static bool fullCalibrated()  { return boardCalibrated() && trashCalibrated; }

// ── EEPROM persistence ───────────────────────────────────────────────────────
// Layout: [0..3] magic "CALB" | [4..35] eight floats h1X,h1Y,a1X,a1Y,h8X,h8Y,trashX,trashY | [36] XOR checksum
static const int     EEPROM_CAL_ADDR = 0;
static const uint8_t CAL_MAGIC[4]    = { 'C', 'A', 'L', 'B' };
static const int     EEPROM_CAL_LEN  = 37;

static bool loadCalFromEEPROM() {
  for (int i = 0; i < 4; i++)
    if (EEPROM.read(EEPROM_CAL_ADDR + i) != CAL_MAGIC[i]) return false;
  uint8_t cs = 0;
  for (int i = 0; i < EEPROM_CAL_LEN - 1; i++) cs ^= EEPROM.read(EEPROM_CAL_ADDR + i);
  if (cs != EEPROM.read(EEPROM_CAL_ADDR + EEPROM_CAL_LEN - 1)) return false;
  float buf[8];
  for (int i = 0; i < 8; i++) EEPROM.get(EEPROM_CAL_ADDR + 4 + i * 4, buf[i]);
  h1X = buf[0]; h1Y = buf[1];
  a1X = buf[2]; a1Y = buf[3];
  h8X = buf[4]; h8Y = buf[5];
  trashX = buf[6]; trashY = buf[7];
  h1Calibrated = a1Calibrated = h8Calibrated = trashCalibrated = true;
  return true;
}

static void saveCalToEEPROM() {
  for (int i = 0; i < 4; i++) EEPROM.update(EEPROM_CAL_ADDR + i, CAL_MAGIC[i]);
  EEPROM.put(EEPROM_CAL_ADDR + 4,  h1X);
  EEPROM.put(EEPROM_CAL_ADDR + 8,  h1Y);
  EEPROM.put(EEPROM_CAL_ADDR + 12, a1X);
  EEPROM.put(EEPROM_CAL_ADDR + 16, a1Y);
  EEPROM.put(EEPROM_CAL_ADDR + 20, h8X);
  EEPROM.put(EEPROM_CAL_ADDR + 24, h8Y);
  EEPROM.put(EEPROM_CAL_ADDR + 28, trashX);
  EEPROM.put(EEPROM_CAL_ADDR + 32, trashY);
  uint8_t cs = 0;
  for (int i = 0; i < EEPROM_CAL_LEN - 1; i++) cs ^= EEPROM.read(EEPROM_CAL_ADDR + i);
  EEPROM.update(EEPROM_CAL_ADDR + EEPROM_CAL_LEN - 1, cs);
}

static void clearCalEEPROM() {
  for (int i = 0; i < EEPROM_CAL_LEN; i++) EEPROM.update(EEPROM_CAL_ADDR + i, 0xFF);
}

// ── Calibration wizard ───────────────────────────────────────────────────────
// Walks user through H1 -> A1 -> H8 -> Trash. 'v' locks, 'n' skips,
// 'p' goes back, 'q' cancels and reverts. Saves to EEPROM when all 4 done.
enum CalStep : uint8_t { CAL_H1 = 0, CAL_A1 = 1, CAL_H8 = 2, CAL_TRASH = 3 };
static CalStep calStep = CAL_H1;

// Snapshot: saved on entering cal mode, restored on cancel
static bool  snapH1c, snapA1c, snapH8c, snapTrashc;
static float snapH1X, snapH1Y, snapA1X, snapA1Y, snapH8X, snapH8Y;
static float snapTrashX, snapTrashY;

static const char* calCornerName(CalStep s) {
  if (s == CAL_H1)    return "H1";
  if (s == CAL_A1)    return "A1";
  if (s == CAL_H8)    return "H8";
  return "Trash";
}

static bool calCornerSaved(CalStep s) {
  if (s == CAL_H1)    return h1Calibrated;
  if (s == CAL_A1)    return a1Calibrated;
  if (s == CAL_H8)    return h8Calibrated;
  return trashCalibrated;
}

static void calGetSavedXY(CalStep s, float& x, float& y) {
  if (s == CAL_H1)       { x = h1X;    y = h1Y; }
  else if (s == CAL_A1)  { x = a1X;    y = a1Y; }
  else if (s == CAL_H8)  { x = h8X;    y = h8Y; }
  else                   { x = trashX; y = trashY; }
}

static void captureCalCorner(CalStep s) {
  if (s == CAL_H1)       { h1X = arm.x(); h1Y = arm.y(); h1Calibrated = true; }
  else if (s == CAL_A1)  { a1X = arm.x(); a1Y = arm.y(); a1Calibrated = true; }
  else if (s == CAL_H8)  { h8X = arm.x(); h8Y = arm.y(); h8Calibrated = true; }
  else { trashX = arm.x(); trashY = arm.y(); trashCalibrated = true; }
  Serial.print("[cal] "); Serial.print(calCornerName(s));
  Serial.print(" set to ("); Serial.print(arm.x()); Serial.print(", "); Serial.print(arm.y());
  Serial.println(")");
}

static void snapshotCal() {
  snapH1c = h1Calibrated; snapH1X = h1X; snapH1Y = h1Y;
  snapA1c = a1Calibrated; snapA1X = a1X; snapA1Y = a1Y;
  snapH8c = h8Calibrated; snapH8X = h8X; snapH8Y = h8Y;
  snapTrashc = trashCalibrated; snapTrashX = trashX; snapTrashY = trashY;
}

static void restoreCalSnapshot() {
  h1Calibrated = snapH1c; h1X = snapH1X; h1Y = snapH1Y;
  a1Calibrated = snapA1c; a1X = snapA1X; a1Y = snapA1Y;
  h8Calibrated = snapH8c; h8X = snapH8X; h8Y = snapH8Y;
  trashCalibrated = snapTrashc; trashX = snapTrashX; trashY = snapTrashY;
}

static void promptCalStep(CalStep s) {
  Serial.println("====================================");
  Serial.print("[cal] Step "); Serial.print((int)s + 1); Serial.print("/4: ");
  Serial.println(calCornerName(s));
  if (s == CAL_TRASH)
    Serial.println("  Move arm to trash position (XY only — Z is hardcoded in config).");
  if (calCornerSaved(s)) {
    float tx, ty; calGetSavedXY(s, tx, ty);
    Serial.print("  saved=("); Serial.print(tx); Serial.print(", "); Serial.print(ty);
    Serial.println(") — moving there. Nudge to fine-tune.");
    if (!arm.moveXY(tx, ty))
      Serial.println("  WARNING: saved position unreachable. Jog manually.");
  } else {
    Serial.println("  no saved value — move arm here manually.");
  }
  Serial.println("  wasd/uj=jog  v=validate  n=skip  p=prev  q=cancel");
  Serial.println("====================================");
}

static void enterCalModeAt(CalStep startStep) {
  if (calibrationMode) return;
  calibrationMode = true;
  snapshotCal();
  calStep = startStep;
  Serial.println("Calibration mode ON");
  Serial.print("  H1:    "); Serial.println(h1Calibrated    ? "saved" : "MISSING");
  Serial.print("  A1:    "); Serial.println(a1Calibrated    ? "saved" : "MISSING");
  Serial.print("  H8:    "); Serial.println(h8Calibrated    ? "saved" : "MISSING");
  Serial.print("  Trash: "); Serial.println(trashCalibrated ? "saved" : "MISSING");
  promptCalStep(calStep);
}

static void enterCalMode() {
  enterCalModeAt(CAL_H1);
}

static void finishCalMode() {
  calibrationMode = false;
  if (fullCalibrated()) {
    saveCalToEEPROM();
    Serial.println("[cal] All 4 points set. Saved to EEPROM.");
  } else {
    Serial.println("[cal] Incomplete — not all points set. EEPROM unchanged.");
    Serial.print("  H1    "); Serial.println(h1Calibrated    ? "OK" : "MISSING");
    Serial.print("  A1    "); Serial.println(a1Calibrated    ? "OK" : "MISSING");
    Serial.print("  H8    "); Serial.println(h8Calibrated    ? "OK" : "MISSING");
    Serial.print("  Trash "); Serial.println(trashCalibrated ? "OK" : "MISSING");
  }
}

static void cancelCalMode() {
  calibrationMode = false;
  restoreCalSnapshot();
  Serial.println("[cal] Cancelled. Reverted to prior values.");
}

// ── Square → XY ─────────────────────────────────────────────────────────────
static bool squareToXY(char file, int rank, float& outX, float& outY) {
  if (!boardCalibrated()) return false;
  if (file < 'a' || file > 'h') return false;
  if (rank < 1   || rank > 8)   return false;
  int fileIdx   = file - 'a';
  int rankIdx   = rank - 1;
  float vFileX  = (a1X - h1X) / 7.0f, vFileY = (a1Y - h1Y) / 7.0f;
  float vRankX  = (h8X - h1X) / 7.0f, vRankY = (h8Y - h1Y) / 7.0f;
  int fileFromH = 7 - fileIdx;
  outX = h1X + fileFromH * vFileX + rankIdx * vRankX;
  outY = h1Y + fileFromH * vFileY + rankIdx * vRankY;
  return true;
}

// ── Capture helpers (direct commands, outside wizard) ───────────────────────
static void captureH1() {
  h1X = arm.x(); h1Y = arm.y(); h1Calibrated = true;
  Serial.println("====================================");
  Serial.print("H1 CAPTURED  XY=("); Serial.print(h1X); Serial.print(", "); Serial.print(h1Y); Serial.println(")");
  Serial.println("====================================");
}
static void captureA1() {
  a1X = arm.x(); a1Y = arm.y(); a1Calibrated = true;
  Serial.println("====================================");
  Serial.print("A1 CAPTURED  XY=("); Serial.print(a1X); Serial.print(", "); Serial.print(a1Y); Serial.println(")");
  Serial.println("====================================");
}
static void captureH8() {
  h8X = arm.x(); h8Y = arm.y(); h8Calibrated = true;
  Serial.println("====================================");
  Serial.print("H8 CAPTURED  XY=("); Serial.print(h8X); Serial.print(", "); Serial.print(h8Y); Serial.println(")");
  Serial.println("====================================");
}
static void captureTrash() {
  trashX = arm.x(); trashY = arm.y(); trashCalibrated = true;
  Serial.println("====================================");
  Serial.print("TRASH CAPTURED XY=("); Serial.print(trashX); Serial.print(", ");
  Serial.print(trashY); Serial.println(")");
  Serial.println("====================================");
}

// ── Piece helpers ────────────────────────────────────────────────────────────
static int pieceNameToType(String pieceName) {
  pieceName.toLowerCase();
  if (pieceName == "pawn")   return PAWN;
  if (pieceName == "knight") return KNIGHT;
  if (pieceName == "bishop") return BISHOP;
  if (pieceName == "rook")   return ROOK;
  if (pieceName == "queen")  return QUEEN;
  if (pieceName == "king")   return KING;
  return -1;
}

// ── Key classification ───────────────────────────────────────────────────────
static bool isCmKey(char c) {
  return c == 'w' || c == 'a' || c == 's' || c == 'd'
      || c == 'u' || c == 'j'
      || c == 'c' || c == 'v'
      || c == 'q';
}

static bool isCalKey(char c) {
  return c == 'w' || c == 'a' || c == 's' || c == 'd'
      || c == 'u' || c == 'j'
      || c == 'v' || c == 'n' || c == 'p' || c == 'q';
}

// ── Help ─────────────────────────────────────────────────────────────────────
static void printCmHelp() {
  Serial.println("------ controller mode keys ------");
  Serial.println("  w/a/s/d : jog XY (+/- 3 mm)");
  Serial.println("  u/j     : jog Z  (+/- 1.5 mm)");
  Serial.println("  c/v     : close / open gripper");
  Serial.println("  q       : exit controller mode");
  Serial.println("----------------------------------");
}

// ── Command handler ───────────────────────────────────────────────────────────
static void handleCommand(String cmd) {
  cmd.trim();
  if (cmd.length() == 0) return;

  if (cmd.length() == 1) {

    // ── Calibration wizard keys ──────────────────────────────────────────────
    if (calibrationMode) {
      if (cmd == "q") { cancelCalMode(); return; }

      if (cmd == "v") {
        captureCalCorner(calStep);
        if (calStep == CAL_TRASH) { finishCalMode(); return; }
        calStep = (CalStep)(calStep + 1);
        promptCalStep(calStep);
        return;
      }
      if (cmd == "n") {
        if (calStep == CAL_TRASH) { finishCalMode(); return; }
        calStep = (CalStep)(calStep + 1);
        promptCalStep(calStep);
        return;
      }
      if (cmd == "p") {
        if (calStep == CAL_H1) { Serial.println("[cal] already at first corner"); return; }
        calStep = (CalStep)(calStep - 1);
        promptCalStep(calStep);
        return;
      }

      bool moved = true;
      if      (cmd == "w") arm.moveXY(arm.x(), arm.y() + CAL_JOG_XY_MM);
      else if (cmd == "s") arm.moveXY(arm.x(), arm.y() - CAL_JOG_XY_MM);
      else if (cmd == "a") arm.moveXY(arm.x() - CAL_JOG_XY_MM, arm.y());
      else if (cmd == "d") arm.moveXY(arm.x() + CAL_JOG_XY_MM, arm.y());
      else if (cmd == "u") arm.moveByZ( CAL_JOG_Z_MM);
      else if (cmd == "j") arm.moveByZ(-CAL_JOG_Z_MM);
      else moved = false;

      if (moved) {
        Serial.print("[cal "); Serial.print(calCornerName(calStep)); Serial.print("] pos=(");
        Serial.print(arm.x()); Serial.print(", ");
        Serial.print(arm.y()); Serial.print(", ");
        Serial.print(arm.z()); Serial.println(")");
      }
      return;
    }

    // ── Controller mode keys ─────────────────────────────────────────────────
    if (controllerMode) {
      if (cmd == "q") {
        controllerMode = false;
        Serial.println("Controller mode OFF");
        return;
      }

      bool moved = true;
      if      (cmd == "w") arm.moveXY(arm.x(), arm.y() + JOG_XY_MM);
      else if (cmd == "s") arm.moveXY(arm.x(), arm.y() - JOG_XY_MM);
      else if (cmd == "a") arm.moveXY(arm.x() - JOG_XY_MM, arm.y());
      else if (cmd == "d") arm.moveXY(arm.x() + JOG_XY_MM, arm.y());
      else if (cmd == "u") arm.moveByZ( JOG_Z_MM);
      else if (cmd == "j") arm.moveByZ(-JOG_Z_MM);
      else if (cmd == "c") { arm.closeGripper(); Serial.println("Gripper: CLOSED"); return; }
      else if (cmd == "v") { arm.openGripper();  Serial.println("Gripper: OPEN");   return; }
      else moved = false;

      if (moved) {
        Serial.print("[cm] pos=(");
        Serial.print(arm.x()); Serial.print(", ");
        Serial.print(arm.y()); Serial.print(", ");
        Serial.print(arm.z()); Serial.println(")");
      }
      return;
    }

    // ── Raw step jog ─────────────────────────────────────────────────────────
    if (cmd == "f") {
      beforeMove();
      xStepper.setDirection(true); xStepper.step(); arm.sync(); stepCount++;
      afterMove();
    } else if (cmd == "b") {
      beforeMove();
      xStepper.setDirection(false); xStepper.step(); arm.sync(); stepCount--;
      afterMove();
    } else if (cmd == "w") {
      beforeMove();
      yStepper.setDirection(true); yStepper.step(); arm.sync(); stepCount++;
      afterMove();
    } else if (cmd == "s") {
      beforeMove();
      yStepper.setDirection(false); yStepper.step(); arm.sync(); stepCount--;
      afterMove();
    } else if (cmd == "u") {
      beforeMove();
      zStepper.setDirection(true); zStepper.step(); stepCount++;
      afterMove();
    } else if (cmd == "d") {
      beforeMove();
      zStepper.setDirection(false); zStepper.step(); stepCount--;
      afterMove();
    } else if (cmd == "c") {
      arm.closeGripper(); return;
    } else if (cmd == "v") {
      arm.openGripper(); return;
    }

    Serial.print("Position: "); Serial.print(stepCount); Serial.println(" steps");

  } else {

    // ── Multi-char commands ───────────────────────────────────────────────────
    if (cmd == "OG") {
      arm.openGripper();
      Serial.println("done");
    } else if (cmd == "CG") {
      arm.closeGripper();
      Serial.println("done");
    } else if (cmd == "GS") {
      Serial.println(arm.gripperOpen() ? "Gripper: open" : "Gripper: closed");

    } else if (cmd.startsWith("GA ")) {
      arm.setGripperAngle(cmd.substring(3).toFloat());

    } else if (cmd.startsWith("jogJ1 ")) {
      float deg = cmd.substring(6).toFloat();
      arm.moveJ1(arm.j1Angle() + deg);
      Serial.print("[jog] J1 -> "); Serial.println(arm.j1Angle());
      Serial.println("done");

    } else if (cmd.startsWith("jogJ2 ")) {
      float deg = cmd.substring(6).toFloat();
      arm.moveJ2(arm.j2Angle() + deg);
      Serial.print("[jog] J2 -> "); Serial.println(arm.j2Angle());
      Serial.println("done");

    } else if (cmd.startsWith("jogZ ")) {
      float mm = cmd.substring(5).toFloat();
      arm.moveByZ(mm);
      Serial.print("[jog] Z -> "); Serial.println(arm.z());
      Serial.println("done");

    } else if (cmd.startsWith("angleX ")) {
      arm.moveJ1(cmd.substring(7).toFloat());

    } else if (cmd.startsWith("angleY ")) {
      arm.moveJ2(cmd.substring(7).toFloat());

    } else if (cmd.startsWith("moveXY ")) {
      String vals = cmd.substring(7);
      int sp = vals.indexOf(' ');
      float x = vals.substring(0, sp).toFloat();
      float y = vals.substring(sp + 1).toFloat();
      Serial.print("Moving to X: "); Serial.print(x); Serial.print(", Y: "); Serial.println(y);
      arm.moveXY(x, y);

    } else if (cmd.startsWith("moveZ ")) {
      float mm = cmd.substring(6).toFloat();
      Serial.print("Moving Z to: "); Serial.print(mm); Serial.println(" mm");
      arm.moveZ(mm);

    } else if (cmd.startsWith("moveXYZ ")) {
      String vals = cmd.substring(8);
      int sp1 = vals.indexOf(' ');
      int sp2 = vals.indexOf(' ', sp1 + 1);
      float x = vals.substring(0, sp1).toFloat();
      float y = vals.substring(sp1 + 1, sp2).toFloat();
      float z = vals.substring(sp2 + 1).toFloat();
      Serial.print("Moving to X: "); Serial.print(x);
      Serial.print(", Y: "); Serial.print(y);
      Serial.print(", Z: "); Serial.println(z);
      arm.moveXYZ(x, y, z);

    } else if (cmd == "home") {
      Serial.println("Going home: J1=0, J2=0, Z=hover");
      arm.goHome();
      Serial.println("home done");

    } else if (cmd.startsWith("pick ")) {
      String vals = cmd.substring(5);
      int sp = vals.indexOf(' ');
      if (sp < 0) { Serial.println("usage: pick <piece> <square>"); return; }
      String pieceName = vals.substring(0, sp);
      String sq = vals.substring(sp + 1);
      pieceName.trim(); sq.trim(); sq.toLowerCase();
      int pieceType = pieceNameToType(pieceName);
      if (pieceType < 0) { Serial.println("Invalid piece. Use: pawn, knight, bishop, rook, queen, king"); return; }
      if (sq.length() != 2) { Serial.println("usage: pick <piece> <square>, e.g. pick pawn e2"); return; }
      char file = sq.charAt(0);
      int  rank = sq.charAt(1) - '0';
      float tx, ty;
      if (!squareToXY(file, rank, tx, ty)) {
        Serial.println(boardCalibrated() ? "bad square (use a1..h8)" : "Board not fully calibrated. Run `cal`.");
        return;
      }
      Serial.print("Pick "); Serial.print(pieceName); Serial.print(" from "); Serial.print(sq);
      Serial.print(" -> XY("); Serial.print(tx); Serial.print(", "); Serial.print(ty); Serial.println(")");
      if (!arm.pickAt(tx, ty, pieceType)) Serial.println("Pick failed"); else Serial.println("Pick done");

    } else if (cmd.startsWith("put ")) {
      String vals = cmd.substring(4);
      int sp = vals.indexOf(' ');
      if (sp < 0) { Serial.println("usage: put <piece> <square|trash>"); return; }
      String pieceName = vals.substring(0, sp);
      String sq = vals.substring(sp + 1);
      pieceName.trim(); sq.trim(); sq.toLowerCase();
      bool toTrash = (sq == "trash");
      int pieceType = pieceNameToType(pieceName);
      if (pieceType < 0) { Serial.println("Invalid piece. Use: pawn, knight, bishop, rook, queen, king"); return; }
      float tx, ty;
      if (toTrash) {
        if (!trashCalibrated) { Serial.println("Trash not calibrated. Use setTrash first."); return; }
        tx = trashX; ty = trashY; // Note: trashZ is hardcoded in config
      } else {
        if (sq.length() != 2) { Serial.println("usage: put <piece> <square|trash>"); return; }
        char file = sq.charAt(0);
        int  rank = sq.charAt(1) - '0';
        if (!squareToXY(file, rank, tx, ty)) {
          Serial.println(boardCalibrated() ? "bad square (use a1..h8)" : "Board not fully calibrated. Run `cal`.");
          return;
        }
      }
      if (toTrash) {
        Serial.print("Put "); Serial.print(pieceName); Serial.print(" to trash -> XYZ(");
        Serial.print(tx); Serial.print(", "); Serial.print(ty); Serial.print(", "); Serial.print(TRASH_Z); Serial.println(")");
        if (!arm.moveXYZ(tx, ty, PICKPLACE_HOVER_Z_MM)) Serial.println("Put failed");
        else { arm.openGripper(); Serial.println("Put done"); }
      } else {
        Serial.print("Put "); Serial.print(pieceName); Serial.print(" to "); Serial.print(sq);
        Serial.print(" -> XY("); Serial.print(tx); Serial.print(", "); Serial.print(ty); Serial.println(")");
        if (!arm.putAt(tx, ty, pieceType)) Serial.println("Put failed"); else Serial.println("Put done");
      }

    } else if (cmd == "calibrate") {
      arm.calibrate();
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
void loop() {
  updateDrivers();

  // The ESP32 UI box now talks to Python over WiFi. The Mega's USB Serial is
  // reserved for arm commands from Python, so do not let UIController consume it.

  while (Serial.available()) {
    char c = Serial.read();
    if (c == '\r') continue;

    // In cm / cal mode, action keys dispatch immediately (no Enter needed) so
    // that holding the key auto-repeats into continuous motion. Multi-char
    // commands still work because their letters aren't action keys.
    if (controllerMode && isCmKey(c)) {
      handleCommand(String(c));
      continue;
    }
    if (calibrationMode && isCalKey(c)) {
      handleCommand(String(c));
      continue;
    }

    if (c == '\n') {
      handleCommand(cmdBuffer);
      cmdBuffer = "";
    } else {
      cmdBuffer += c;
    }
  }
}

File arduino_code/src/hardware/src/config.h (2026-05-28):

#ifndef CONFIG_H
#define CONFIG_H
/**
 * config.h defines mechanical variables to drive the movement of the arm
 * 
 * The values are measured on the physical arm
 */


const unsigned int DEFAULT_STEP_DELAY_US = 300;

// Motor
const int MICROSTEPS = 16;
const float STEPS_PER_REV  = 200.0f;

// Gear ratios
const int   DRIVING_TEETH_j2 = 18;
const int   DRIVING_TEETH_j1 = 20;
const int   JOINT_TEETH = 105;
const int   BASE_TEETH = 160;

const float GEAR_RATIO_J2 = (float)DRIVING_TEETH_j2 / JOINT_TEETH;
const float GEAR_RATIO_J1 = (float)DRIVING_TEETH_j1 / BASE_TEETH;

// Arm link lengths (mm)
const float LINK1_LENGTH = 250.0f;
const float LINK2_LENGTH = 250.0f;
const float LINK3_LENGTH = 290.0f;  // lead screw / Z

// Lead screw
const float Z_MAX_MM = LINK3_LENGTH;
const float STARTS = 4.0f;
const float PITCH = 2.0f;
const float LEAD = STARTS * PITCH;
const float STEPS_PER_MM = STEPS_PER_REV * 2 / LEAD;
const float GRIPPER_LENGTH  = 100.0f;

// Gripper
const int OPEN_ANGLE = 65;
const int CLOSED_ANGLE = 0;

// Chess piece types (used for pick/place Z height lookup)
enum ChessPiece {
  PAWN = 0,
  KNIGHT = 1,
  BISHOP = 2,
  ROOK = 3,
  QUEEN = 4,
  KING = 5
};

// Pick/place Z presets per piece type (mm)
// Common hover/travel height (safe for all pieces)
const float PICKPLACE_HOVER_Z_MM = 90.0f;

// Pick Z (lower to grip) per piece type
const float PICK_Z[6] = {
  7.0f,  // PAWN
  3.0f,  // KNIGHT
  11.0f,  // BISHOP
  10.0f,  // ROOK
  14.0f,  // QUEEN
  14.0f   // KING
};

// Place Z (lower to set down) per piece type
const float PLACE_Z[6] = {
  17.0f,  // PAWN
  13.0f,  // KNIGHT
  21.0f,  // BISHOP
  20.0f,  // ROOK
  24.0f,  // QUEEN
  24.0f   // KING
};

// Trash position Z (hardcoded, not calibrated)
const float TRASH_Z = 90.0f;

#endif

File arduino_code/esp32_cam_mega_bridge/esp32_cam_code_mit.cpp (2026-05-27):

#include "esp_camera.h"
#include <WiFi.h>
#include <WebServer.h>

// =========================
// WiFi
// =========================
const char* ssid = "SPOT-iot";
const char* password = "VitreuseLoukoumManquante7702";

// =========================
// AI Thinker ESP32-CAM pins
// =========================
#define PWDN_GPIO_NUM     32
#define RESET_GPIO_NUM    -1
#define XCLK_GPIO_NUM      0
#define SIOD_GPIO_NUM     26
#define SIOC_GPIO_NUM     27

#define Y9_GPIO_NUM       35
#define Y8_GPIO_NUM       34
#define Y7_GPIO_NUM       39
#define Y6_GPIO_NUM       36
#define Y5_GPIO_NUM       21
#define Y4_GPIO_NUM       19
#define Y3_GPIO_NUM       18
#define Y2_GPIO_NUM        5
#define VSYNC_GPIO_NUM    25
#define HREF_GPIO_NUM     23
#define PCLK_GPIO_NUM     22

// =========================
// Serial connection to Arduino Mega
// Based on your current wiring:
//
// ESP32-CAM GPIO3 -> Mega pin 19 / RX1
// ESP32-CAM GPIO1 -> Mega pin 18 / TX1
//
// Therefore:
// ESP32 receives from Mega TX1 on GPIO1
// ESP32 sends to Mega RX1 on GPIO3
// =========================
HardwareSerial MegaSerial(2);

#define MEGA_RX_PIN 1    // ESP32 receives data from Mega TX1 / pin 18
#define MEGA_TX_PIN 3    // ESP32 sends data to Mega RX1 / pin 19
#define MEGA_BAUD   9600

WebServer server(80);

// =========================
// Camera options API
// =========================
int parseIntArg(const String &name, int defaultValue) {
  if (!server.hasArg(name)) {
    return defaultValue;
  }

  return server.arg(name).toInt();
}

void handleOptions() {
  sensor_t *s = esp_camera_sensor_get();

  if (!s) {
    server.send(500, "application/json", "{\"ok\":false,\"error\":\"sensor_unavailable\"}");
    return;
  }

  bool applied = false;

  if (server.hasArg("brightness")) {
    s->set_brightness(s, parseIntArg("brightness", 0));
    applied = true;
  }
  if (server.hasArg("contrast")) {
    s->set_contrast(s, parseIntArg("contrast", 0));
    applied = true;
  }
  if (server.hasArg("saturation")) {
    s->set_saturation(s, parseIntArg("saturation", 0));
    applied = true;
  }
  if (server.hasArg("denoise")) {
    s->set_denoise(s, parseIntArg("denoise", 0));
    applied = true;
  }
  if (server.hasArg("gainceiling")) {
    s->set_gainceiling(s, (gainceiling_t)parseIntArg("gainceiling", 0));
    applied = true;
  }
  if (server.hasArg("quality")) {
    s->set_quality(s, parseIntArg("quality", 12));
    applied = true;
  }
  if (server.hasArg("awb")) {
    s->set_whitebal(s, parseIntArg("awb", 1));
    applied = true;
  }
  if (server.hasArg("awb_gain")) {
    s->set_awb_gain(s, parseIntArg("awb_gain", 1));
    applied = true;
  }
  if (server.hasArg("wb_mode")) {
    s->set_wb_mode(s, parseIntArg("wb_mode", 0));
    applied = true;
  }
  if (server.hasArg("exposure_ctrl")) {
    s->set_exposure_ctrl(s, parseIntArg("exposure_ctrl", 1));
    applied = true;
  }
  if (server.hasArg("aec_value")) {
    s->set_aec_value(s, parseIntArg("aec_value", 300));
    applied = true;
  }
  if (server.hasArg("ae_level")) {
    s->set_ae_level(s, parseIntArg("ae_level", 0));
    applied = true;
  }
  if (server.hasArg("gain_ctrl")) {
    s->set_gain_ctrl(s, parseIntArg("gain_ctrl", 1));
    applied = true;
  }
  if (server.hasArg("agc_gain")) {
    s->set_agc_gain(s, parseIntArg("agc_gain", 0));
    applied = true;
  }
  if (server.hasArg("special_effect")) {
    s->set_special_effect(s, parseIntArg("special_effect", 0));
    applied = true;
  }
  if (server.hasArg("hmirror")) {
    s->set_hmirror(s, parseIntArg("hmirror", 0));
    applied = true;
  }
  if (server.hasArg("vflip")) {
    s->set_vflip(s, parseIntArg("vflip", 0));
    applied = true;
  }

  String response = "{\"ok\":";
  response += (applied ? "true" : "false");
  response += "}";
  server.send(200, "application/json", response);
}

// =========================
// Web page
// =========================
void handleRoot() {
  String html = R"rawliteral(
    <!DOCTYPE html>
    <html>
    <head>
      <meta charset="utf-8">
      <title>ESP32-CAM Test</title>
      <style>
        body {
          font-family: Arial, sans-serif;
          text-align: center;
          margin-top: 30px;
          background: #f5f5f5;
        }
        img {
          width: 480px;
          border: 1px solid #ccc;
          margin-top: 20px;
          background: white;
        }
        button {
          font-size: 16px;
          padding: 10px 20px;
          margin-top: 10px;
          cursor: pointer;
        }
        .controls {
          width: 520px;
          margin: 20px auto;
          padding: 15px 20px;
          background: #ffffff;
          border: 1px solid #ddd;
          border-radius: 8px;
          text-align: left;
        }
        .row {
          display: flex;
          align-items: center;
          gap: 10px;
          margin: 8px 0;
        }
        .row label {
          flex: 0 0 120px;
          font-size: 14px;
          color: #333;
        }
        .row input[type="range"] {
          flex: 1;
        }
        .value {
          width: 40px;
          text-align: right;
          font-size: 13px;
          color: #555;
        }
        .toggle {
          display: flex;
          align-items: center;
          gap: 8px;
          font-size: 14px;
          color: #333;
          margin: 8px 0;
        }
        .info {
          margin-top: 15px;
          font-size: 14px;
          color: #555;
        }
      </style>
    </head>
    <body>
      <h1>ESP32-CAM Basic Test</h1>
      <p>Click to capture a new image.</p>

      <button onclick="refreshImage()">Capture</button>

      <div>
        <img id="photo" src="/capture?t=0" alt="camera image">
      </div>
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

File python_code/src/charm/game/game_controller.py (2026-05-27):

from __future__ import annotations

import json
import threading
import time
from dataclasses import dataclass
from pathlib import Path
from typing import Callable, Optional

import chess
import serial

from charm.arduino.uiController_bridge import ArduinoUIControllerLink
from charm.arduino.arduino_bridge import execute_move, send_command
from charm.chess_engine import (
    Evaluation,
    classify_move_rating,
    evaluate_position,
    format_score,
    win_percentage_from_cp,
    winning_color,
)
from charm.game.cv_scan import build_router, persist_validated_capture
from charm.game.game_session import GameSession, SessionResult
from charm.vision.cv_router import AttemptDecision


# Move-quality term flashed on the LCD (mirrors api_server._RATING_LCD_LABEL).
_RATING_LCD_LABEL = {
    "Blunder": "BLUNDER!",
    "Mistake": "MISTAKE!",
    "Inaccuracy": "INACCURACY",
    "Good": "GOOD",
    "Excellent": "EXCELLENT!",
}


# Shared with webapp_backend/api_server.py — both must resolve to the same
# absolute path (python_code/controller_game_state.json) so the webapp can
# poll the LCD-driven game state.
_CONTROLLER_STATE_FILE = (
    Path(__file__).resolve().parents[3] / "controller_game_state.json"
)


BoardImageProvider = Callable[[], str]
MoveExecutor = Callable[[], None]
DifficultyHandler = Callable[[int], None]
PhaseListener = Callable[[str, Optional[str], Optional[str]], None]
ScanListener = Callable[[dict], None]
EvaluationListener = Callable[[dict], None]


@dataclass
class GameControllerConfig:
    """Wires the game/session layer to the Arduino UI protocol.

    The controller does not decide chess moves itself. It only coordinates:
    - UI state events coming from the Arduino UIController
    - session/vision checks
    - external move planning/execution callbacks supplied by the app layer
    """
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

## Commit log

2026-04-02 defined the arduino pins
2026-04-04 Add new version of the inverse kinematics implementation for robotic arm
    fix the issues and added the gear ratio one
    [inverse_kinematics2.ino]
2026-04-04 Add Arduino code for robotic arm control
2026-04-04 Change name of file to ArduinoCode.ino
2026-04-04 New version of the inverse kinematics functionality for robotic arm
    fix the issues and added the gear ration one
    [inverse_kinematics2.ino]
2026-04-14 Add: the second version of the movement control code
    - add the gear ratio
    - fix some small bugs
    [inverse_kinematics.ino]
2026-04-14 added arduino code
2026-04-18 Add: Chessboard recognition and focusing on the chessboard
    1. read an input image,
    2. detect the board region,
    3. warp it into a top-down view,
    4. overlay an 8x8 debug grid.
2026-04-18 Add: Implement baseline chessboard vision pipeline with board detection, occupancy, and piece color classification
    - occupancy detection
    - piece color classification
2026-04-18 I added the limit switches, homing, added the lead screw and added commands for moving in postitions with inverse kinematics and for homing
2026-04-19 I forgot to take into account the length of the gripper, but now it's up to date
2026-04-19 I added the gripper mechanism for opening and closing
2026-04-20 Added chess state tracking from board bitmaps
2026-04-21 Add: The end-to-end game session flow with initial board validation and move recognition
    - game session
2026-04-23 added limit switch pins and servo pin
2026-04-26 I added the bridge from python.code to arduino (but it's not finished yet)
2026-04-28 Add: add Stockfish-based best move computation prototype
    - the game_session, best_move are the core files
    - the demo_game_session and demo_stockfish are the tests methodes
2026-04-28 Fix: delect the import arduino
    - fix the run problem
    [game_session.py]
2026-04-29 I tried to fix the issue with the calibration and the stepsPerDegree, but I'm not sure if it's correct -> I have to test it out again
    [config.h, gripper.cpp, limitAxis.cpp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]
2026-04-30 I calibrated for the inverse kinematics and the correct limit switch code
    [config.h, limitAxis.cpp, main.cpp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]
2026-05-03 Add button input and LCD display hardware abstraction
2026-05-04 add Arduino UI controller flow and Python game bridge integration
2026-05-04 Add: Refactor CV pipeline to use manual board calibration and simplified bitmap recognition
    - new CV processing and tests
2026-05-05 deleted the long press button of back -> could cause problems in electronics
    [buttonInput.cpp, uiController.cpp]
2026-05-06 fix(scara): correct joint2 inversion and Z calibration offset
    - ScaraArm: negate theta2 when commanding joint2 and when reading it
    back for FK; the joint2 motor's positive direction is opposite to the
    IK CCW convention, which produced mirrored end-effector positions
    for any non-zero elbow bend.
    - main.cpp calibration: drop the redundant setZero() after the 30 mm
    lift so position_mm() reflects actual height above the bottom switch.
    - main.cpp setup: re-enable gripper.begin().
    - gripper: use openAngle on begin and qualify servo with this->.
    - config: set OPEN_ANGLE to 65.
    [config.h, gripper.cpp, main.cpp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]
2026-05-06 feat(serial): add controller mode with continuous wasd/u/j jog and v/c gripper
    - New `controllerMode` / `cm` toggle; in this mode w/a/s/d jog XY, u/j
    jog Z, v/c open/close gripper. Single-char keys dispatch immediately
    (no Enter required) so terminal key-repeat produces continuous motion.
    - Each jog calls arm.sync() before computing the target so a clamped
    joint can't accumulate drift in the requested XY.
    - Add v/c gripper shortcuts in normal mode as well.
    - Refresh the boot help banner.
    [main.cpp]
2026-05-07 Add: new image and the new calibration value
    - image and json value
2026-05-07 Add: add the arduino camera control code and changed the python code to adopted
    - add the camera control code .ino
    - changed the python transferphoto.py to adopt the new camera setup
2026-05-12 Flip rank direction in chess square mapping
    Ranks now extend in -Y from H1 instead of +Y, matching board orientation.
    [main.cpp]
2026-05-12 Subdivide moveXY into 1mm substeps for straight-line Cartesian motion
    Joints still move sequentially per substep, but per-substep arc error is
    negligible (<1mm), so the end-effector traces a near-straight line instead
    of the two-arc path seen on Y jogs. Revert with git revert if needed.
    [scaraArm.cpp]
2026-05-12 Replace single-corner SQUARE_MM calibration with 3-corner affine map
    Calibrate by capturing arm XY at A1, H1, and H8. Any square's position is
    built by vector decomposition from H1 using two basis vectors:
    vFile = (a1 - h1) / 7 (per file, h -> a)
    vRank = (h8 - h1) / 7 (per rank, 1 -> 8)
    P(file, rank) = h1 + (7 - fileIdx) * vFile + rankIdx * vRank
    Sidesteps the ~8% kinematic scale error: as long as all three corners
    share the same scaling/skew, it cancels within the board area.
    New commands: setA1, setH8 (parallel to existing setH1).
    New cm-mode shortcuts: 1=setA1, 8=setH8 (h=setH1 unchanged).
    boardInfo now prints all three corners plus derived basis vectors and
    their magnitudes (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
    [main.cpp]
2026-05-12 board calibration works
2026-05-12 Rework board calibration + lead-screw microstep + drop residual tracking
    - Strip H1/A1/H8 captures from controller mode; add a `cal` wizard that
    walks H1 -> A1 -> H8 with wasd/uj jog, v/n/p/q controls, and EEPROM
    persistence (magic CALB + XOR checksum at addr 0). Saved values load
    automatically on boot.
    - Move the steps/mm math into LeadScrew (mirrors ScaraJoint): constructor
    now takes stepsPerRev/microstep/lead_mm and exposes stepsPerMm(). Drop
    the precomputed STEPS_PER_MM constant from config.h.
    - Remove stepResidual carry-rounding from both ScaraJoint and LeadScrew,
    and track currentAngle/currentMm against the physically-emitted step
    count rather than the commanded delta. Th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
    [leadScrew.cpp, main.cpp, scaraArm.cpp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]
2026-05-12 Drop 1mm substepping in moveXY; sweep j1 then j2
    Single IK on the target, run joint1.moveTo to completion, then joint2.
    The arm traces an arc (j1) then a second arc (j2) rather than a straight
    Cartesian line. Z must be kept high during goto so the intermediate arc
    clears any pieces.
2026-05-13 I added a rest function for the drivers (still has to be checked and accepted) and added missing function in main for trash capturing
    [main.cpp, scaraArm.cpp]
2026-05-13 I corrected the trash capturing
    [arduino_bridge.py, config.h, main.cpp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]
2026-05-13 Refactor: adjust font size in occupancy debug and update white threshold for piece color detection; add two-step calibration script and corresponding test
2026-05-15 WIP: Local changes to Arduino, Python vision/game, and webapp
2026-05-16 Working with webapp: vision capture fixes, game controller, Arduino UI integration
    - Fix pawn promotion ambiguity in state_tracker (skip non-queen variants)
    - Fix en passant crash in arduino_bridge (correct captured pawn square)
    - Fix robot promotion: send promoted piece type in put command
    - Integrate ArduinoUIControllerLink with GameController
    - Update webapp frontend and backend for calibration and game flow
    [arduino_bridge.py, buttonInput.cpp, config.h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]
2026-05-16 Rest position at (0,500), Arduino tests, project files, cleanup
    - Change goHome() rest position from (500,0) to (0,500): J1=90deg, J2=0deg
    - Add Arduino test mains: main_lcd_test, main_sim_test, main_ui_test
    - Add project root files: README, LICENSE, proposal, wiring diagram
    - Add robot_calibration.json and webapp calibration snapshots
    - Remove obsolete debug outputs, coordinate_map, test files
2026-05-19 see issues but mainly some CV tuning
    [game_session.py, vision_integration.py]
2026-05-20 checkpoint: WIP labeling wizard before sweep fix
    [config.h, main.cpp, scaraArm.cpp]
2026-05-20 CNN training fixes, standalone trainer, labeling wizard improvements
    - Fix class imbalance: apply sample_weight to both train and val so
    val_loss/val_accuracy reflect the balanced objective; removes silent
    bias toward predicting empty on empty-heavy validation sets
    - Add EarlyStopping + ReduceLROnPlateau; count class weights from disk
    instead of iterating the full dataset before training starts
    - Add train_standalone.py: single-file trainer requiring only TF +
    matplotlib, for running on a GPU machine without the full project
    - BulkPaintBoard component and labeling wizard sweep/bulk-paint flow
    - Update .gitignore to exclude venv, labeled_datasets, models, snapshots
2026-05-20 Wire CNN model into game loop; remove classical pipeline from game scans
    When a CNN model is activated in the lab, game/session/start and
    game/session/player-done now use the CNN path: warp the raw image,
    classify all 64 cells in one forward pass, and feed the resulting
    bitmaps directly into the game tracker. No occupancy thresholds, no
    color-ratio heuristics — just the model output.
    When no CNN model is active the classical pipeline is used as fallback
    so nothing breaks if the model hasn't been trained yet.
    New in game_session.py:
    - initialize_from_bitmaps(): CNN entry point for session init
    - process_bitmaps(): CNN entry point for move detection
    New in api_server.py:
    - _run_cnn_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
    [game_session.py]
2026-05-21 Dashboard: replace classical CV with CNN model picker and clean vision card
    - Remove all threshold/occupancy/color-ratio UI: params modal, Tune CV
    button, empty reference capture, Pipeline test button, the 8-panel
    debug grid (board edges, grid, occupancy, piece colors, preprocessed)
    - Add CNN model selector: header chip shows active model + val accuracy,
    clicking opens a modal listing all trained runs with activate buttons
    - Vision Pipeline card renamed to CNN Vision; debug panels reduced to
    Refined Warp + CNN Scan overlay
    - Bottom overlay now shows warp + CNN overlay instead of classical debug
    - Add cnn_overlay / cnn_active fields to PipelineResult type
    - HeaderSystemStatus gains a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
2026-05-21 Docs: detailed CV/CNN implementation guide; Update calibrations
2026-05-21 fixed things need to add cnn
    [arduino_bridge.py, config.h, esp32_ui_box.cpp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]
2026-05-21 arm calibration odesn't wokr but lcd does
2026-05-21 everything fixed just want implementation with lcd to interact with the webapp
    [leadScrew.cpp]
2026-05-21 fixed cnn training + fully working lcd and webapp
    [game_controller.py, robot_adapter.py]
2026-05-22 implement LCD enhancements: turns, difficulty slider, error messages, manual control, bot move display, board flip, startup flow, player/bot promotion, check notification, encoder debounce
    [arduino_bridge.py, buttonInput.cpp, game_controller.py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]
2026-05-23 fix encoder debounce, bot move display, arm sync, and misc wiring
    - Encoder: gate on CLK HIGH after each event to prevent bounce double-clicks
    - LCD: don't re-format bot move on ESP32, Python already sends display string
    - scaraArm: fix afterMove() call order in moveXYZ; add before/afterMove to moveJ1/J2
    - main.cpp: add "done" responses so Python bridge detects command completion
    - game_controller.py: run first bot move in background thread to avoid BOARD_TIMEOUT
    [arduino_bridge.py, buttonInput.cpp, game_controller.py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]
2026-05-23 fixed the lcd black and white play
    [game_controller.py]
2026-05-26 Added Electrical Circuit and Explanation
2026-05-26 Update gripper description in README
    Removed the approximate offset detail for the gripper.
2026-05-27 added updated BOM
    [bill-of-materials.csv]
2026-05-27 Add: Enhance README.md with detailed explanations of game logic and calibration processes
2026-05-27 readme ui box and arduino adds
2026-05-28 added dxf and stl files
    [arm_bearing_hold.stl, base.stl, base_bearing_insert.stl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]
2026-05-28 added CAD image
2026-05-28 feat : add images of final arm assembly on the README
2026-05-31 Update README to specify aluminum for joint components
    Specify material for critical joint components to aluminum.
